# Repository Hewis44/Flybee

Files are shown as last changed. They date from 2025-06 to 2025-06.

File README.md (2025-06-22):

# Flybee – Autonomous Fixed-Wing UAV
Flybee is a fully homegrown, lightweight, and modular autonomous fixed-wing UAV that I developed from scratch as part of my passion for aeromodelling and autonomous systems. Since childhood, I was fascinated by how aircraft fly and always dreamt of building my own drone. With Flybee, that dream started taking real shape. The idea was not just to make a drone that flies, but to design everything myself—from the aerodynamic layout to the structure and control system—so I could understand how each part contributes to the whole flight system. The design process was completely done in Onshape, where I iterated on the airframe layout several times, focusing on balancing aerodynamic performance, ease of manufacturing, and structural strength. I used a high-wing configuration with a rectangular wing planform to ensure passive stability, which is very helpful for autonomous flight and easier for tuning during initial flights.

I carefully compared multiple airfoils such as the S1223 and NACA4412 using CFD simulations and lift-drag plots, and finally selected the GOE225 airfoil for its balanced characteristics across different speeds and angles of attack. For the tail, I wanted to reduce the number of moving surfaces and mechanical parts, so I designed a V-tail, which was then blended into the fuselage to reduce drag and weight while keeping it aesthetically clean and functional. Every part of the frame—wing ribs, fuselage sections, and tail pieces—was later transferred to Fusion 360 to validate alignment and fit. After finalising the dimensions and checking tolerances, I exported them as DXF files suitable for laser cutting. These are included in this repository and can be used as-is on balsa or aeroply sheets.



The structure is lightweight and strong enough for mid-range autonomous missions. I chose materials like balsa wood and aeroply because they’re easy to work with, locally available, and provide a good weight-to-strength ratio. Assembly was done using adhesives like Araldite and Fevicol Marine, and I used Monokote film to cover the airframe, giving it a polished look while also adding some resistance to moisture and wear. All these steps were carried out manually in a small home workshop setup, making this a purely DIY project from start to finish.




On the electronics side, the UAV is powered by a Pixhawk 2.4.8 flight controller, along with a Ublox Neo-M8N GPS module, telemetry radios, and basic power distribution. The autopilot was configured using Mission Planner, which allows full waypoint missions, geofencing, and RTL (Return To Launch) features. I also used the FlySky FS-i6 transmitter and iA6B receiver for manual override and initial ground testing. The motor is a powerful T-Motor AS2820 1050KV paired with a 60A ESC and a 13-inch propeller, all running on a 3S 3300mAh LiPo battery. During development, I put a lot of effort into wire management and power distribution to keep the internals neat and reliable. The aircraft’s internal bay was designed to be modular so that future upgrades like camera gimbals or advanced sensors can be easily added.

While most of the structural and design work is complete, the UAV is currently undergoing flight testing. I am fine-tuning the PID parameters and testing different mission profiles in open fields nearby. The first flights are being done manually to trim the control surfaces and validate center of gravity, followed by semi-autonomous and full-autonomous tests. I plan to log flight data and refine the performance based on real-world feedback, which will later help in optimizing the structure and maybe even designing a second version.

This repository contains only the laser cutting files for now, but they represent the complete airframe, ready to be fabricated and assembled. In the future, I will also try to upload build photos, wiring diagrams, and maybe a full setup guide for others who wish to build their own version of Flybee. The project was developed for the Highways Hackclub under the builder alias Hewis_lamilton, and I hope it can serve as a starting point for other students, hobbyists, or aero clubs looking to dive into fixed-wing autonomous flight. If you’re curious or inspired to build, feel free to fork, modify, or even reach out. This project is meant to be shared, improved, and flown.

Made for Highways by Hewis_lamilton

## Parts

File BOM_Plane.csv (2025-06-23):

Component | Model | Quantity | Unit Price (INR) | Total Price (INR) | USD Price (Approx) | Supplier
----------------- | --------------------------- | -------- | ---------------- | ----------------- | ------------------ | -----------
Flight Controller | Ardupilot | 1 | 5,499 | 5,499 | $63.54 | Amazon.in
GPS Module | Ublox Neo-M8N GPS + Compass | 1 | 2120 | 2120 | $24.45 | Amazon.in
Motor | T-Motor AS2820 1050KV | 1 | 3199 | 3199 | $36.88 | DRKStore.in
ESC | 60A ESC (AT75A or similar) | 1 | 3500 | 3500 | $40.34 | DRKstore.in
Battery | 3S 3300mAh LiPo | 1 | 2200 | 2200 | $25.00 | Hitechxyz.in
Propeller | 13 inch Propeller | 1 | 350 | 350 | $4.03 | Hitechxyz.in
Receiver | FlySky iA6B | 1 | 1300 | 1300 | $14.98 | Local store
Transmitter | FlySky FS-i6 | 1 | 4200 | 4200 | $48.41 | Local store
Servos | MG90S Metal Gear | 3 | 250 | 750 | $8.64 | Local store
Wing Material | Balsa + Birch Spars | 1 | 1000 | 1000 | $11.53 | Local Store
Fuselage Material | Balsa + Aeroply | 1 | 800 | 800 | $9.22 | Local Store
Covering | Monokote & Adhesives | 1 | 1200 | 1200 | $13.83 | Local Store
Miscellaneous | Glue, Hinges, Wires | 1 | 500 | 500 | $5.76 | Local Store
**TOTAL** |  |  |  | **₹26558** | **$306.8**

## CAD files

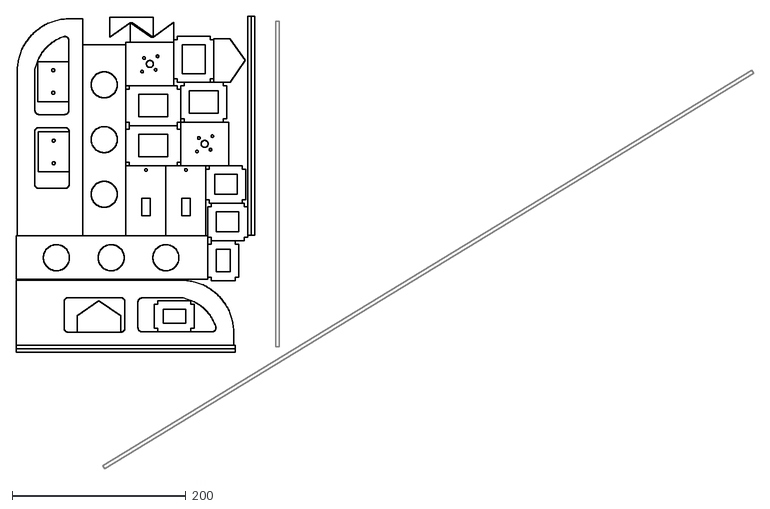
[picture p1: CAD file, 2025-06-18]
Files/allParts+sparsLong.dxf
848.2 x 520.7

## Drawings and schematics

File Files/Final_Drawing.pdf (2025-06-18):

6
5

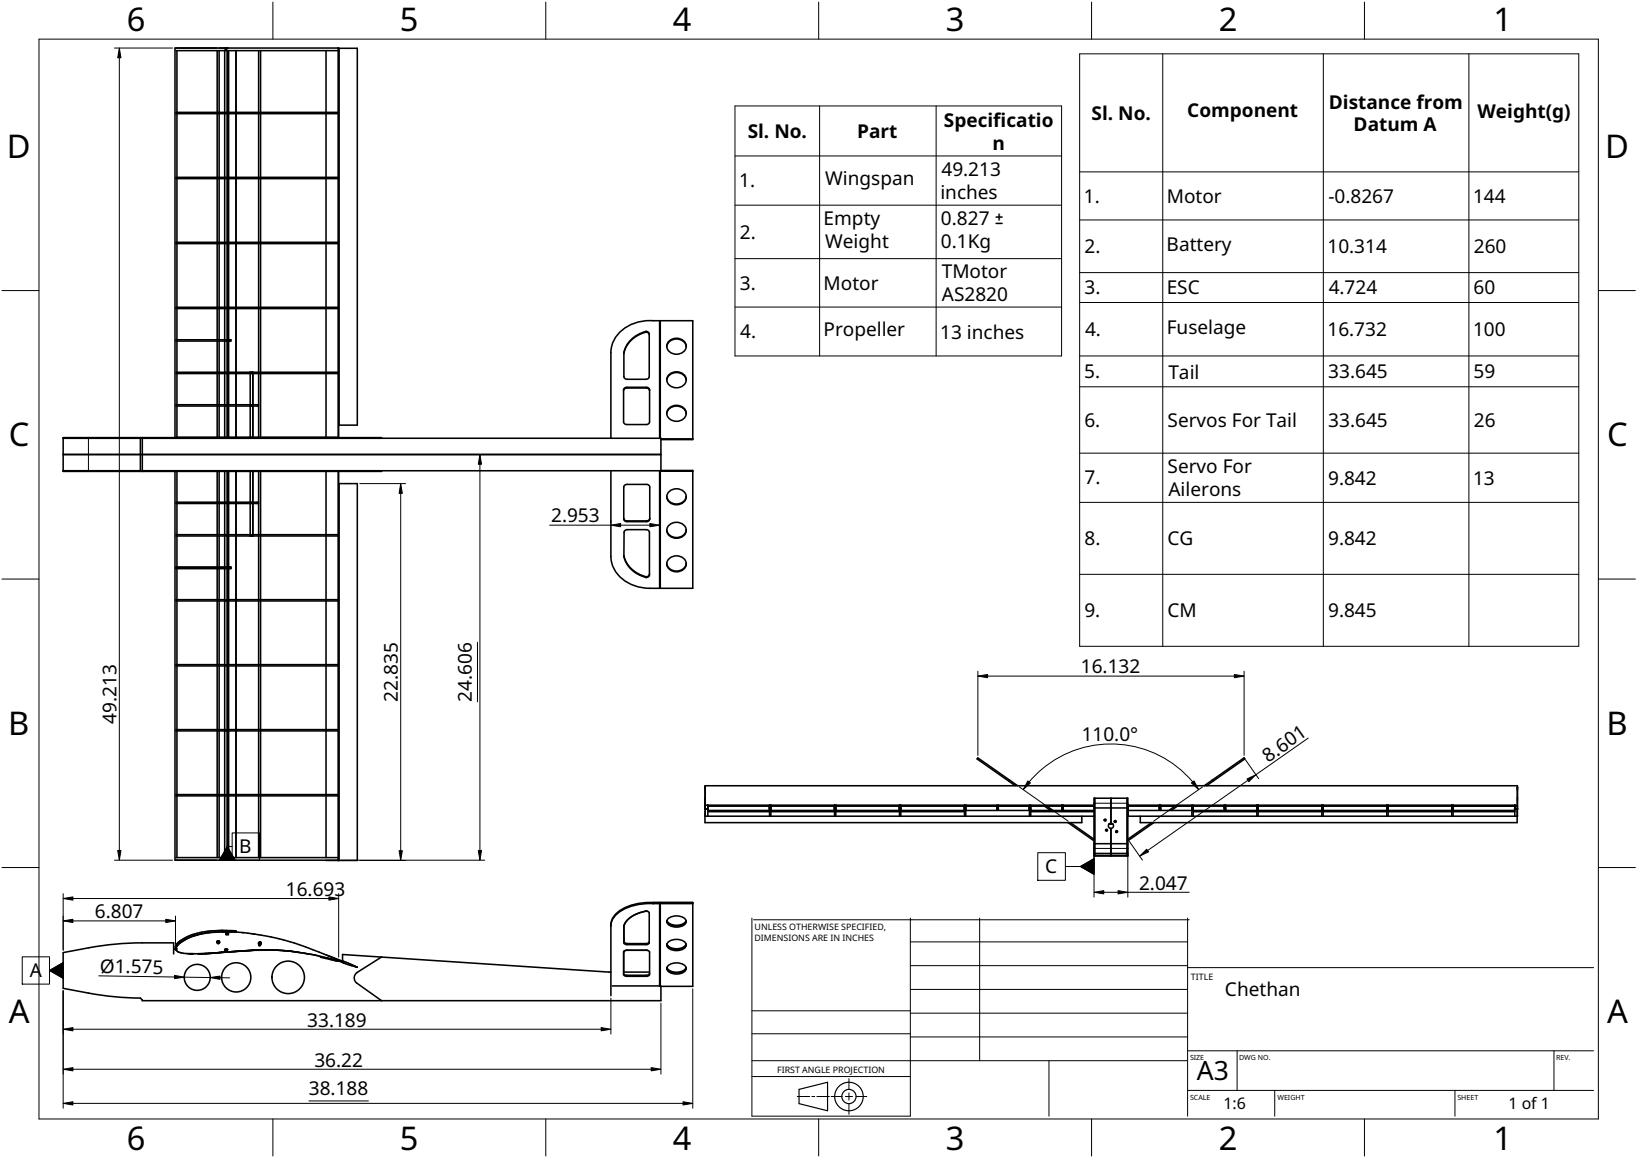
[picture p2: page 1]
TITLE; SIZE A3; DWG NO.; REV.; SCALE; WEIGHT; SHEET; Chethan

Sl. No. | Component | Distance from Datum A | Weight(g)

Sl. No. | Part | Specificatio n

1. | Wingspan | 49.213 inches

1. | Motor | -0.8267 | 144

2. | Empty Weight | 0.827 ± 0.1Kg

2. | Battery | 10.314 | 260

3. | Motor | TMotor AS2820

3. | ESC | 4.724 | 60

4. | Propeller | 13 inches

4. | Fuselage | 16.732 | 100

5. | Tail | 33.645 | 59

6. | Servos For Tail | 33.645 | 26

7. Servo For | Ailerons | 9.842 | 13

UNLESS OTHERWISE SPECIFIED,
DIMENSIONS ARE IN INCHES

FIRST ANGLE PROJECTION

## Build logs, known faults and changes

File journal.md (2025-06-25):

---
Title: "A Fixed Wing Aircraft"
Author: "Hewis44"
Description: "UAV"
created_at: "2025-06-13"
Total time spent: 48-50 Hours
---

## Day 1, 13th JUNE – Design, Modelling & Initial CFD , Research ( 15-20 HOURS)

So yeah, this whole thing started with a simple idea — to make a cool fixed-wing plane that can lift good weight but still be light and easy to carry. I wanted something that works well, flies smooth, and isn’t a pain to assemble. Once I had the goal in mind, I just jumped into it step by step planning the design, picking the parts, and figuring out how to actually build it all.



***Honestly Evryone Should try this***

At the beginning of this whole fixed-wing project, I had literally no clue how to use CAD or CFD tools properly. Like I had seen people using stuff like SolidWorks or Fusion 360, but my laptop wasn’t that powerful, so I didn’t want to install anything heavy. That’s when I found Onshape, and bro it was honestly a game-changer. It runs fully in the browser, so I didn’t even need to worry about lag or anything. I used it to make every single part of the plane — the fuselage, the wing structure, the tail, everything. It was clean and pretty simple to understand once you get used to the interface. For learning how to do all that properly, I followed tutorials from YouTube channels like CAD CAM Tutorials, Joko Engineeringhelp, and Product Design Online. They explained small things like how to use constraints properly, how to mirror sketches, and how to do fillets and assemblies. I literally used to keep one side of my screen for YouTube and the other side for Onshape and copy whatever they were doing until I got my design working. Joko’s channel helped me understand how to model symmetric parts and wings, especially how to make proper parametric sketches so I could edit later easily.

Follow this playlist For learning ansys:https://youtube.com/playlist?list=PLykANdmho34xuMaku22umA1xP6vidDfIN&si=9iTnEPpwRTiwWmO0

Then came the CFD part, and man, it was a different level. I decided to use ANSYS Fluent for the simulations because it gives very detailed results, and I wanted to check lift and drag values accurately. But ANSYS looked very pro-level in the beginning, and it took me a full day just to understand what a boundary condition is. I started slow by watching videos on channels like LearnCAx, CAx Tutorials, and SimuTech Group. These channels go step-by-step, like first they show how to import geometry (I exported my wing as a STEP file from Onshape), then how to clean up the model in ANSYS SpaceClaim, and then how to create mesh, apply freestream conditions, and finally simulate. At first I was just copying whatever they were doing, but after a while I started understanding why they were using k-omega SST model and how the mesh refinement near the surface actually affects the boundary layer results. One of the most useful parts was learning how to run an AoA sweep and see how the lift changes at each angle. That’s how I confirmed that GOE225 airfoil was giving more lift and better stall behaviour than others I tested. Also learned how to generate those nice colorful contour plots showing pressure and velocity lines. The simulation part honestly felt very satisfying when I saw the air flow properly over my wing, and no weird flow separations. If I had not followed those YouTube tutorials, especially from LearnCAx and SimuTech Group, I don’t think I could’ve figured it out on my own. So yeah, a big chunk of this project was basically me learning from YouTube and then applying it directly to my own design. Pure desi jugaad style learning, but it worked.

### 15 JUNE: Planning the Design & Frame Style   ( TOOK WHOLE ETRNITY)        20 HOURS

I started by scribbling a basic sketch of the UAV, mainly to fix what mattered most — modularity, lift, and weight balance. I knew from the start I wanted a high-wing design because it’s naturally more stable and gives better visibility for autopilot. I went for a tractor propeller setup, so airflow over the wing is smooth and undisturbed, especially important during takeoff. I began modelling the fuselage in Onshape — just a simple boxy design first, then slowly refined it to match internal space needs and weight distribution.
Fuselage CAD
Fuselage Screenshot

Once the fuselage looked okay, I shifted focus to the wing design. I kept it rectangular for ease of construction and better roll stability — the span I chose was 1250 mm and chord 250 mm, which gave decent wing area for the expected weight class. For the airfoil, I tested three options: GOE225, S1223, and NACA4412. I compared their Cl/Cd ratio, stall angle, and thickness. GOE225 performed best overall, especially in moderate Reynolds numbers — gave higher lift with manageable drag.

Airfoil Plots
Comparisons

I then modelled the GOE225-based wing on Onshape, adding ribs, spars, and servo slots. I paid extra attention to internal structure for strength without adding too much weight. Ailerons were also added using simple hinges. After assembling everything virtually, I created a solid version of the wing for CFD. This would help me simulate lift and airflow properly before committing to a real build. This whole phase gave me a much clearer idea of what my aircraft will behave like in flight.

GOE225 Modelling
GOE225 Build

Assembled wing + internal structure:

Wing Assembled
Spars
Ailerons

I made a solid version of the wing for CFD:

Solid Wing

---

##  Tail Design, Final CFD, and Autonomy Prep 10 HOURS

Today I spent time getting my wing and fuselage designs ready for laser cutting. I had to take the CAD models and then export all the ribs, spars, and other parts into DXF format. I remembered I had some leftover acrylic sheets from my old school robotics project, so I’m thinking to use those for the motor mounts and servo plates. Then I opened Fusion 360 and did a small stress simulation for fun, like just to see how much weight the wing can take. It showed that if each side handles around 20N, the spars need to be thick enough or maybe I’ll add a carbon tube in the middle just to be safe. Also tried checking how much the tail flexes under yaw movement, and it was not bad actually. I didn’t expect to enjoy this analysis part so much but once you start getting results it becomes addictive. I made a battery bay design also with a small hatch system, so I don’t have to open everything again and again. Hopefully next time I’ll start assembling the frame after I get the parts cut.

Started the day with **V-tail design**. Used two angled stabilizers at 110°, surface area was 70% of conventional H-tail to save weight.

V-Tail CAD
V-Tail Solid

Mounted **servos on tail** and aligned pushrod paths.

Servos on Tail

Then moved to **final assembly:**

Full Assembly

So today I just went all in with CFD stuff. Like, I wanted to really make sure that the airfoil I chose was actually the best, not just by reading somewhere but by seeing the actual data. I compared GOE225 with S1223 and NACA4412 again but this time I ran proper simulations using different angles of attack. I spent a lot of time learning how to set up the mesh properly, 'cause the accuracy depends a lot on that. I tried coarse mesh first but then realized results were not matching, so after trying mid and fine meshes, I figured mid was giving me a good balance of speed and detail. I also learned about turbulence models like k-omega SST and tried that. It gave pretty nice pressure and velocity plots. Honestly, seeing those color maps and streamlines felt satisfying. And finally, even after all the simulations, GOE225 still showed better performance overall, like higher lift and smoother pressure change. S1223 was good too, but it stalled quickly and the pressure difference was kind of too sharp. So yeah, this kind of confirmed that my choice was solid.

Ran **full body CFD** on wing + fuselage + tail.

CFD 1
CFD 2
CFD 3
CFD 4
Full CFD

Final observations:
- GOE225 gave **28.58 N lift** (wing-only) @ 4° AoA
- Full body gave **37.26 N lift**, **3.61 N drag**
- Smooth pressure gradient, no flow separation
- Enough lift margin to carry 2 kg payload safely

Selected GOE225 for its:
- High lift
- Gentle stall
- Low drag
- Simpler fabrication than S1223

---

These were my learnings and some flaws,mistakes i did while modelling this plane:

IMG-20250307-WA0043

The first image (the one with the circular patterns) shows the pressure field with vector lines from the front view. I used this to understand how the flow gets disturbed around the wing tips and how pressure behaves symmetrically across both wings. You can see those big swirling circles — those are basically vortices forming at the tips due to pressure difference from top and bottom of the wing. This was expected, but I was surprised how clean and uniform the pressure distribution was in the mid-section. That gave me confidence that the design isn’t creating sudden turbulence or separation zones in the middle part of the wing.

Watched this video for understanding laminar Flow:


IMG-20250307-WA0044

IMG-20250307-WA0042

these are velocity streamlines over a side cut of the aircraft. Here I used a velocity inlet of 21.59 m/s and watched how air behaves over the GOE225 airfoil plus the fuselage. This result helped me see how the air smoothly accelerates over the curved upper surface of the wing and slows down below, which is exactly what creates lift. The greenish-blue area above the wing means higher velocity (low pressure), and the lower part has lower velocity (high pressure). One mistake I made here was not refining the mesh properly near the surface in my first try, because the results were looking very patchy. Then I increased the inflation layers and refined the near-wall mesh, and finally I got this smooth output. Also, in the third image which is a full-body side view, you can clearly see the velocity gradients around the whole aircraft — especially how the air slows near the tail. That’s something I didn’t consider during early design, so I’ll maybe lift the tail a bit upward in next revision to avoid airflow hitting directly.

IMG-20250307-WA0039

IMG-20250307-WA0040

 the wing section with GOE225 airfoil that I modelled in Onshape. I used a proper spline-based profile and projected it across multiple ribs. Initially, I tried drawing it manually but the accuracy was off. Then I learned to use coordinates from airfoiltools.com and import those into Onshape sketch, and it made a big difference. This helped make a smooth, realistic wing and not just some random rounded shape.

Then the next image shows a close-up pressure contour at wing-root — basically how the pressure is behaving where the wing joins the fuselage. I saw a strong red spot here which might indicate stress point or potential for structural fatigue, so I might reinforce this joint using carbon rods or laser-cut ply parts. This insight would’ve been missed if I didn’t simulate it properly.the last image is another pressure side view, showing again how pressure drops sharply above the wing and rises below it. Even though it looks very colourful, interpreting this helped me understand how smoothly GOE225 behaves at 4° angle of attack without sudden stall or flow separation.

Overall, this CFD phase taught me so much. From learning how to clean geometry, fix mesh errors, apply correct physics models like k-omega SST, and properly interpret the force outputs — every part was something new. I made many silly mistakes at first like assigning wrong inlet speed, forgetting to use symmetry plane, not applying inflation layers, etc. But by doing trial and error and watching those tutorials side by side, I slowly made my way. It’s honestly one of the most satisfying parts of this whole UAV build. Seeing the virtual airflow over a design you made yourself is such a good feeling. It made me realise how powerful CFD is, and now I’m even thinking of trying transient simulations and maybe propeller analysis next.

### Avionics & Autonomy Setup

Component Layout

For the avionics, I decided to go with a fully autonomous setup because I really wanted the aircraft to perform waypoint navigation without any manual control. So I started by placing the key components — a Pixhawk flight controller, Ublox GPS module, and a 433 MHz telemetry radio. Pixhawk is the brain of the UAV and supports advanced control algorithms. I chose it because it's open-source and works perfectly with ArduPilot, which I’m planning to flash onto it. The GPS module is needed for real-time location tracking, and it works hand-in-hand with the Pixhawk to handle autonomous missions. The 433 MHz telemetry module is for sending live data from the UAV to Mission Planner, which I’ll be using on my laptop during test flights.



The layout of these components was done keeping in mind CG balance and vibration isolation. I’m planning to program basic waypoint missions using Mission Planner, where I’ll set takeoff, loiter, and return-to-home commands. After installation, I will do some ground tests like checking servo directions, GPS lock, and telemetry range. Once everything looks good, I’ll go for the maiden autonomous flight. This whole process is new for me, so I’m learning as I go from different YouTube tutorials and ArduPilot forums.

You can get all the documentations about pixhawk here:https://ardupilot.org/copter/docs/common-pixhawk-overview.html

im gonna Add BOM,sketches and laser cutting files in the repo

## Build ( coming soon)

---
